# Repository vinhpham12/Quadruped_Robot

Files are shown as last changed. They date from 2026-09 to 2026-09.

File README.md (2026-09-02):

# Quadruped_Robot
A custom-designed 12-DOF quadruped robot platform featuring a modular 3D-printed chassis and a dedicated embedded controller board.

## Project Structure

* **hardware/**: 
  * `cad/`: Mechanical assembly, STEP files, and 3D printable STL files (SolidWorks).
  * `pcb/`: Custom mainboard schematics, PCB layout, and gerber files (KiCad).

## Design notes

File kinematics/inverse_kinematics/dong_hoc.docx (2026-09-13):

CHÂN TRÁI TRƯỚC

i | θ_i | d_i | a_(i-1) | α_(i-1)
1 | -90+θ_1 | L_0 | L_1 | -90
2 | θ_2 | 0 | 0 | 90
3 | θ_3 | 0 | L_3 | 0
4 | 0 | 0 | L_4 | 0

CHÂN PHẢI TRƯỚC

i | θ_i | d_i | a_(i-1) | α_(i-1)
1 | -90+θ_1 | L_0 | L_1 | -90
2 | θ_2 | 0 | 0 | 90
3 | θ_3 | 0 | L_3 | 0
4 | 0 | 0 | L_4 | 0

CHÂN TRÁI SAU

i | θ_i | d_i | a_(i-1) | α_(i-1)
1 | -90+θ_1 | L_0 | L_1 | -90
2 | θ_2 | 0 | 0 | 90
3 | θ_3 | 0 | L_3 | 0
4 | 0 | 0 | L_4 | 0

CHÂN PHẢI SAU

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

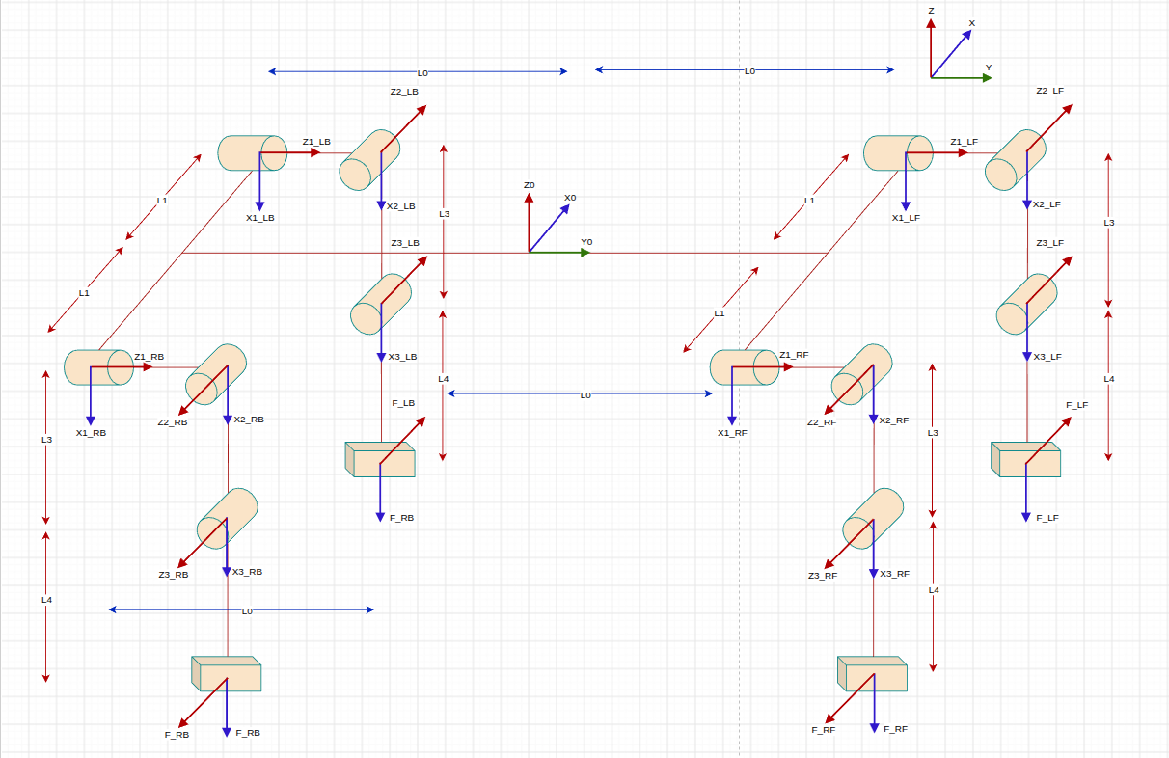
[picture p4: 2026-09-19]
kinematics/inverse_kinematics/Pasted image.png

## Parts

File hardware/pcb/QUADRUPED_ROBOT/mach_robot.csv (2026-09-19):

Reference | Qty | Value | DNP | Exclude from BOM | Exclude from Board | Exclude from Simulation | Exclude from Position Files | Footprint | Datasheet
C1,C2 | 2 | 22pF |  |  |  |  | ${EXCLUDE_FROM_POS_FILES} | Capacitor_SMD:C_0805_2012Metric
C3,C6,C7,C8,C12,C13,C14,C15,C16,C17,C18,C19,C22,C23,C25,C27,C28,C31,C34,C35,C36,C37,C38,C39,C40,C41,C42,C43,C44,C45,C46,C47,C48,C52,C53,C54,C56,C57,C64 | 39 | 100nF |  |  |  |  | ${EXCLUDE_FROM_POS_FILES} | Capacitor_SMD:C_0805_2012Metric
C4,C5 | 2 | 2.2uF |  |  |  |  | ${EXCLUDE_FROM_POS_FILES} | Capacitor_SMD:C_0805_2012Metric
C10 | 1 | 470uF |  |  |  |  | ${EXCLUDE_FROM_POS_FILES} | Capacitor_THT:CP_Radial_D10.0mm_P5.00mm
C11,C26,C50 | 3 | 1uF |  |  |  |  | ${EXCLUDE_FROM_POS_FILES} | Capacitor_SMD:C_0805_2012Metric
C20,C24 | 2 | 1nF |  |  |  |  | ${EXCLUDE_FROM_POS_FILES} | Capacitor_SMD:C_0805_2012Metric
C21 | 1 | 4.7uF |  |  |  |  | ${EXCLUDE_FROM_POS_FILES} | Capacitor_SMD:C_0805_2012Metric
C30,C49,C51 | 3 | 470uF |  |  |  |  | ${EXCLUDE_FROM_POS_FILES} | Capacitor_SMD:CP_Elec_8x10
C32 | 1 | 200uF |  |  |  |  | ${EXCLUDE_FROM_POS_FILES} | Capacitor_Tantalum_SMD:CP_EIA-7343-31_Kemet-D_HandSolder
C33,C58,C60,C61,C62,C63 | 6 | 470uF |  |  |  |  | ${EXCLUDE_FROM_POS_FILES} | Capacitor_Tantalum_SMD:CP_EIA-7343-31_Kemet-D_HandSolder
C55 | 1 | 10uF |  |  |  |  | ${EXCLUDE_FROM_POS_FILES} | Capacitor_SMD:C_0805_2012Metric
C59 | 1 | 10nF |  |  |  |  | ${EXCLUDE_FROM_POS_FILES} | Capacitor_SMD:C_0805_2012Metric
D1,D2,D7,D8,D9,D14 | 6 | LED |  |  |  |  | ${EXCLUDE_FROM_POS_FILES} | LED_SMD:LED_0805_2012Metric
D3 | 1 | D_Zener |  |  |  |  | ${EXCLUDE_FROM_POS_FILES} | Diode_SMD:D_0805_2012Metric
D4 | 1 | SS54 |  |  |  |  | ${EXCLUDE_FROM_POS_FILES} | Diode_SMD:D_SMC
D5 | 1 | SMAJ5.0A |  |  |  |  | ${EXCLUDE_FROM_POS_FILES} | Diode_SMD:D_SMA | https://www.littelfuse.com/media?itemid=75e32973-b177-4ee3-a0ff-cedaf1abdb93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
D6 | 1 | SS1040 |  |  |  |  | ${EXCLUDE_FROM_POS_FILES} | Diode_SMD:D_SMC
D10 | 1 | LED_G |  |  |  |  | ${EXCLUDE_FROM_POS_FILES} | LED_SMD:LED_0805_2012Metric
D11 | 1 | LED_R |  |  |  |  | ${EXCLUDE_FROM_POS_FILES} | LED_SMD:LED_0805_2012Metric
D13 | 1 | SMBJ6.5A |  |  |  |  | ${EXCLUDE_FROM_POS_FILES} | Diode_SMD:D_SMB
F1,F2 | 2 | Fuse |  |  |  |  | ${EXCLUDE_FROM_POS_FILES} | Fuse:Fuseholder_Littelfuse_100_series_5x20mm
J1 | 1 | Conn_01x03_Socket |  |  |  |  | ${EXCLUDE_FROM_POS_FILES} | Connector_PinSocket_2.54mm:PinSocket_1x03_P2.54mm_Vertical
J2 | 1 | Conn_01x04_Pin |  |  |  |  | ${EXCLUDE_FROM_POS_FILES} | Connector_PinSocket_2.54mm:PinSocket_1x04_P2.54mm_Vertical
J3 | 1 | SWITCH_POWER |  |  |  |  | ${EXCLUDE_FROM_POS_FILES} | Connector_PinHeader_2.54mm:PinHeader_1x02_P2.54mm_Vertical
J4,J11,J12,J13,J14,J15,J16,J17,J18,J19,J20,J21,J22 | 13 | Conn_01x03_Pin |  |  |  |  | ${EXCLUDE_FROM_POS_FILES} | Connector_PinHeader_2.54mm:PinHeader_1x03_P2.54mm_Vertical
J5,J10 | 2 | PIN |  |  |  |  | ${EXCLUDE_FROM_POS_FILES} | my_library:TerminalBlock_Phoenix_MKDS-1,5-2-5.08_1x02_P5.08mm_Horizontal
J6 | 1 | USB_C_Receptacle_USB2.0_16P |  |  |  |  | ${EXCLUDE_FROM_POS_FILES} | Connector_USB:USB_C_Receptacle_Amphenol_12401948E412A | https://www.usb.org/sites/default/files/documents/usb_type-c.zip
J7 | 1 | USB_A |  |  |  |  | ${EXCLUDE_FROM_POS_FILES} | Connector_USB:USB_A_Molex_67643_Horizontal
J8 | 1 | Conn_01x05_Pin |  |  |  |  | ${EXCLUDE_FROM_POS_FILES} | Connector_PinSocket_2.54mm:PinSocket_1x05_P2.54mm_Vertical
J9 | 1 | JETSON |  |  |  |  | ${EXCLUDE_FROM_POS_FILES} | my_library:TerminalBlock_Phoenix_MKDS-1,5-2-5.08_1x02_P5.08mm_Horizontal
L1 | 1 | 10uH |  |  |  |  | ${EXCLUDE_FROM_POS_FILES} | Inductor_SMD:L_12x12mm_H6mm
L2 | 1 | 33uH |  |  |  |  | ${EXCLUDE_FROM_POS_FILES} | Inductor_SMD:L_12x12mm_H6mm
Q1 | 1 | AO4485 |  |  |  |  | ${EXCLUDE_FROM_POS_FILES} | Package_SO:SOIC-8_3.9x4.9mm_P1.27mm
Q2,Q3 | 2 | BC847 |  |  |  |  | ${EXCLUDE_FROM_POS_FILES} | Package_TO_SOT_SMD:SOT-23 | http://www.infineon.com/dgdl/Infineon-BC847SERIES_BC848SERIES_BC849SERIES_BC850SERIES-DS-v01_01-en.pdf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
R1 | 1 | 0 |  |  |  |  | ${EXCLUDE_FROM_POS_FILES} | Resistor_SMD:R_0805_2012Metric
R2,R3,R4,R50,R51,R52,R54,R55,R59,R62 | 10 | 10K |  |  |  |  | ${EXCLUDE_FROM_POS_FILES} | Resistor_SMD:R_0805_2012Metric
R5,R8 | 2 | 10m |  |  |  |  | ${EXCLUDE_FROM_POS_FILES} | Resistor_SMD:R_2512_6332Metric
R6 | 1 | 3K |  |  |  |  | ${EXCLUDE_FROM_POS_FILES} | Resistor_SMD:R_0805_2012Metric
R7 | 1 | 50m |  |  |  |  | ${EXCLUDE_FROM_POS_FILES} | Resistor_SMD:R_2512_6332Metric
R9,R10,R38,R41,R42,R43 | 6 | 1K |  |  |  |  | ${EXCLUDE_FROM_POS_FILES} | Resistor_SMD:R_0805_2012Metric
R11 | 1 | 100K |  |  |  |  | ${EXCLUDE_FROM_POS_FILES} | Resistor_SMD:R_0805_2012Metric
R12 | 1 | 5.9k |  |  |  |  | ${EXCLUDE_FROM_POS_FILES} | Resistor_SMD:R_0805_2012Metric
R13,R26,R27,R28,R29,R30,R31,R32,R33,R34,R35,R36,R37 | 13 | 10k |  |  |  |  | ${EXCLUDE_FROM_POS_FILES} | Resistor_SMD:R_0805_2012Metric
R14,R15,R16,R17,R18,R19,R20,R21,R22,R23,R24,R25 | 12 | 100R |  |  |  |  | ${EXCLUDE_FROM_POS_FILES} | Resistor_SMD:R_0805_2012Metric
R39,R40 | 2 | 5.1K |  |  |  |  | ${EXCLUDE_FROM_POS_FILES} | Resistor_SMD:R_0805_2012Metric
R44,R49 | 2 | 270R |  |  |  |  | ${EXCLUDE_FROM_POS_FILES} | Resistor_SMD:R_0805_2012Metric
R45,R48 | 2 | 100k |  |  |  |  | ${EXCLUDE_FROM_POS_FILES} | Resistor_SMD:R_0805_2012Metric
R46,R47 | 2 | 47K |  |  |  |  | ${EXCLUDE_FROM_POS_FILES} | Resistor_SMD:R_0805_2012Metric
R53 | 1 | 20K |  |  |  |  | ${EXCLUDE_FROM_POS_FILES} | Resistor_SMD:R_0805_2012Metric
R56,R63 | 2 | 30K |  |  |  |  | ${EXCLUDE_FROM_POS_FILES} | Resistor_SMD:R_0805_2012Metric
R58,R60 | 2 | 4.7k |  |  |  |  | ${EXCLUDE_FROM_POS_FILES} | Resistor_SMD:R_0805_2012Metric
R61,R64 | 2 | 4.7K |  |  |  |  | ${EXCLUDE_FROM_POS_FILES} | Resistor_SMD:R_0805_2012Metric
SW1 | 1 | SW_Push |  |  |  |  | ${EXCLUDE_FROM_POS_FILES} | my_library:SW_SMD_3x6mm
U1 | 1 | XL4016 |  |  |  |  | ${EXCLUDE_FROM_POS_FILES} | Package_TO_SOT_SMD:TO-263-5_TabPin3 | http://www.xlsemi.net/datasheet/XL4015%20datasheet-English.pdf
U2 | 1 | STM32F723ZETx |  |  |  |  | ${EXCLUDE_FROM_POS_FILES} | Package_QFP:LQFP-144_20x20mm_P0.5mm | https://www.st.com/resource/en/datasheet/stm32f723ze.pdf
U3 | 1 | TPS5430DDA |  |  |  |  | ${EXCLUDE_FROM_POS_FILES} | Package_SO:TI_SO-PowerPAD-8_ThermalVias | http://www.ti.com/lit/ds/symlink/tps5430.pdf
U4 | 1 | USBLC6-2SC6 |  |  |  |  | ${EXCLUDE_FROM_POS_FILES} | Package_TO_SOT_SMD:SOT-23-6 | https://www.st.com/resource/en/datasheet/usblc6-2.pdf
U5 | 1 | INA3221 |  |  |  |  | ${EXCLUDE_FROM_POS_FILES} | Package_DFN_QFN:Texas_RGV0016A_VQFN-16-1EP_4x4mm_P0.65mm_EP2.1x2.1mm | http://www.ti.com/lit/ds/symlink/ina3221.pdf
Y1 | 1 | 25MHz |  |  |  |  | ${EXCLUDE_FROM_POS_FILES} | Crystal:Crystal_HC49-U_Vertical

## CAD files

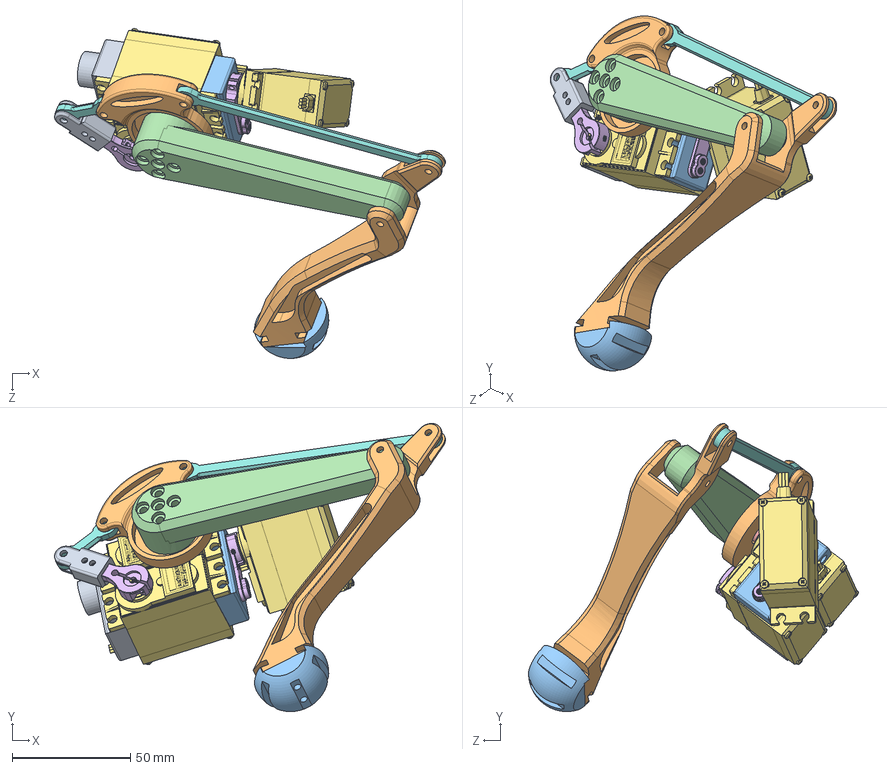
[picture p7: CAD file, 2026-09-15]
hardware/cad/left_foot_after.SLDASM
165.4 x 121.9 x 139.6 mm
MirrorPart78
Servo disc
SERVO ARM HORN 25T ALUMINIUM.step x 2
mg996R_v2.step x 3
noi_3 x 2
noi_chan_1
arm_mod
foot

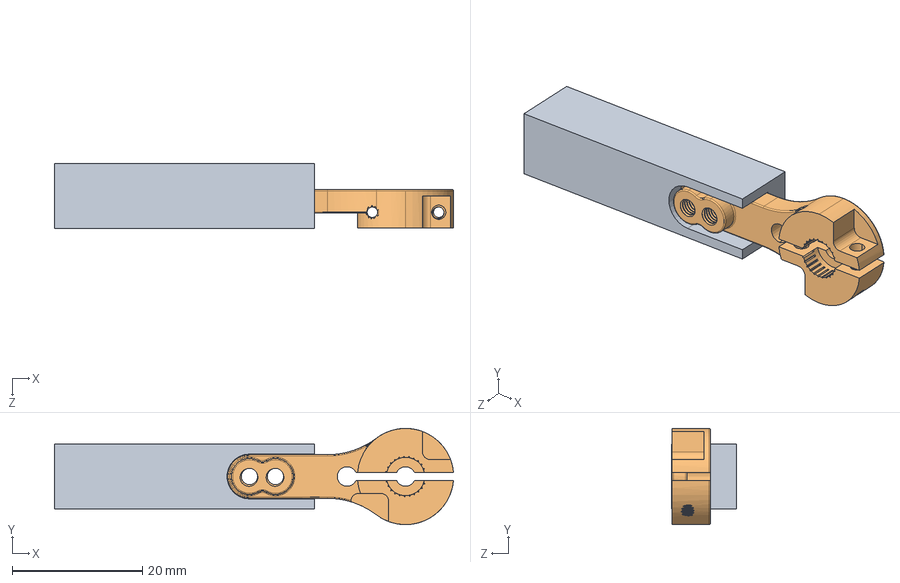
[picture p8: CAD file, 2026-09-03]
hardware/cad/SERVO ARM HORN 25T ALUMINIUM/chan.SLDASM
61.3 x 14.8 x 10.0 mm
noi_chan_1
SERVO ARM HORN 25T ALUMINIUM.step

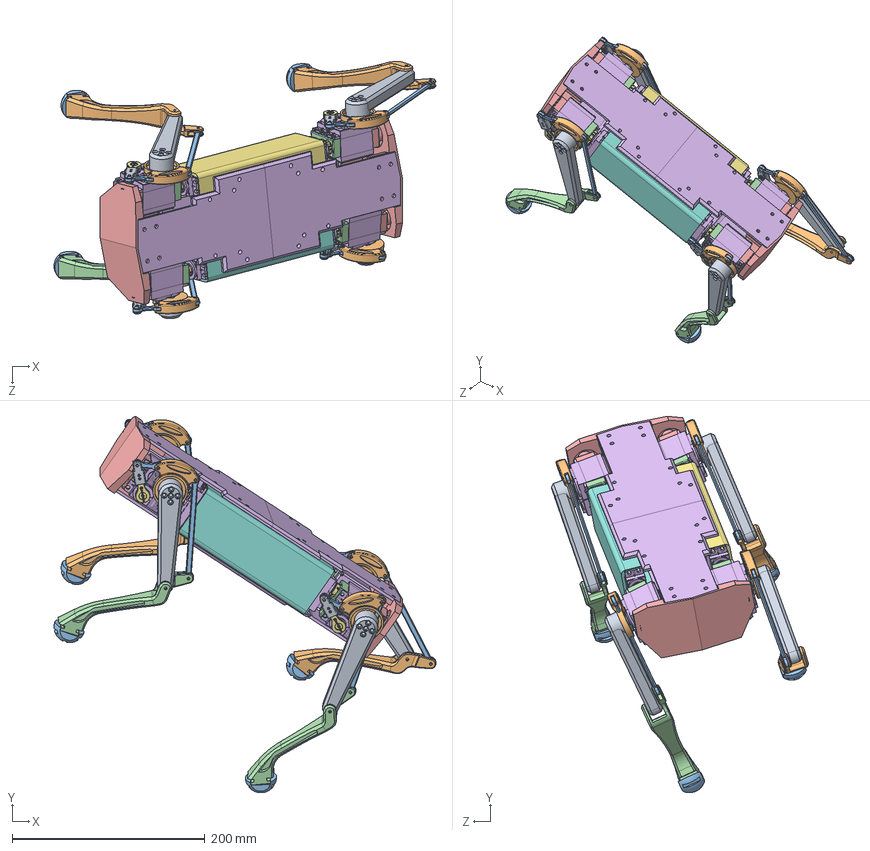
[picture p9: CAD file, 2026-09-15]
hardware/cad/final.SLDASM
395.9 x 390.1 x 266.6 mm
noi_3 x 8
mg996R_v2.step x 12
SERVO ARM HORN 25T ALUMINIUM.step x 8
Servo disc x 4
noi_chan_1 x 4
arm_mod x 4
foot x 4
MirrorPart78 x 2
dau_noi x 2

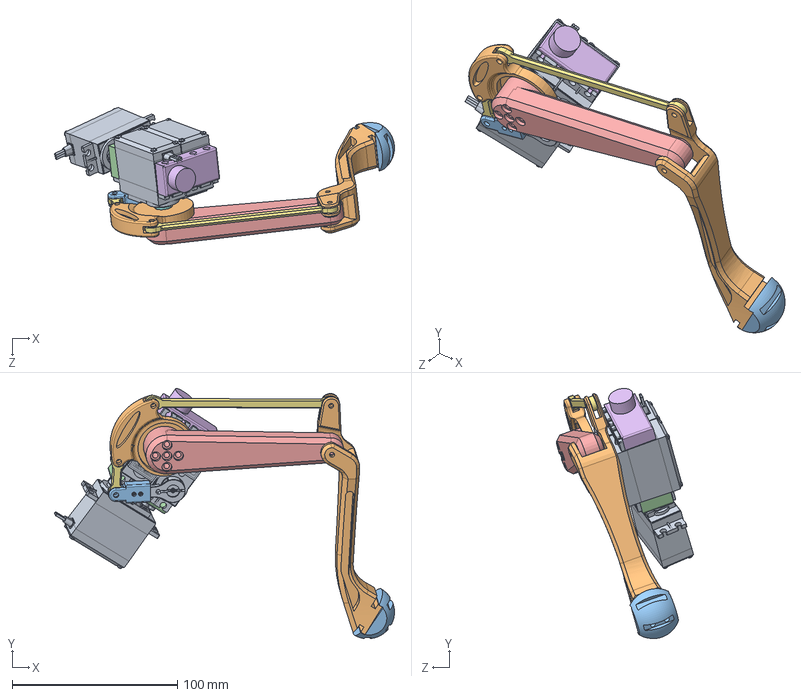
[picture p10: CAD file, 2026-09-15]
hardware/cad/left_foot_back.SLDASM
206.0 x 151.5 x 83.1 mm
mg996R_v2.step x 3
MirrorPart78
noi_chan_1
noi_3 x 2
Servo disc
SERVO ARM HORN 25T ALUMINIUM.step x 2
arm_mod
foot

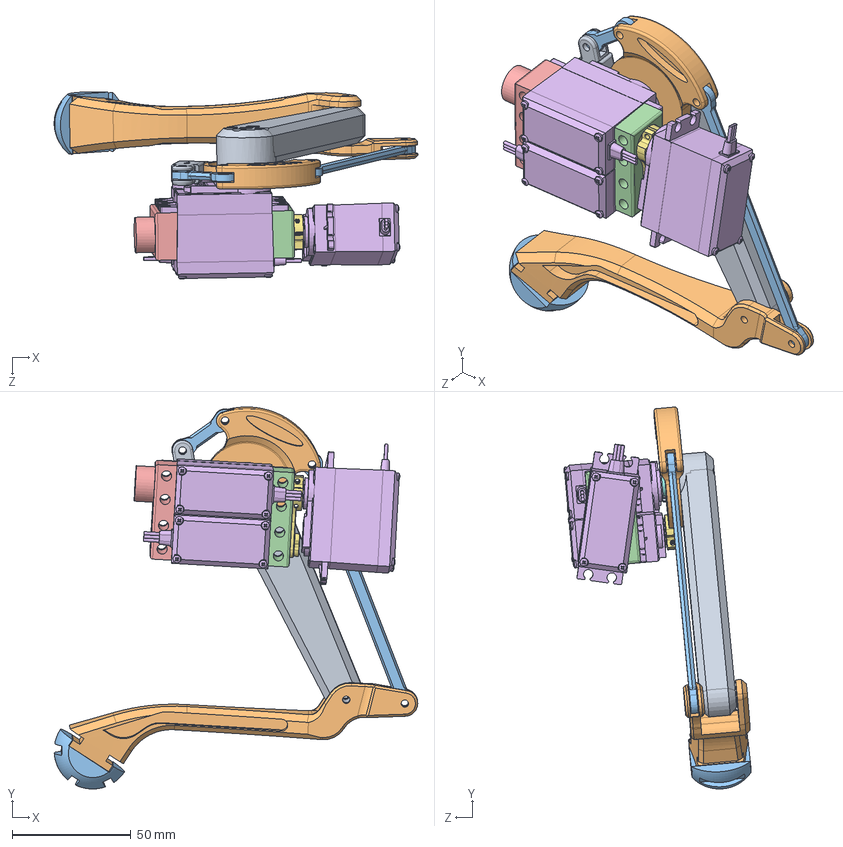
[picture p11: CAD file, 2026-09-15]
hardware/cad/right_foot_after.SLDASM
153.1 x 160.8 x 78.9 mm
noi_3 x 2
mg996R_v2.step x 3
SERVO ARM HORN 25T ALUMINIUM.step x 2
Servo disc
noi_chan_1
arm_mod
foot

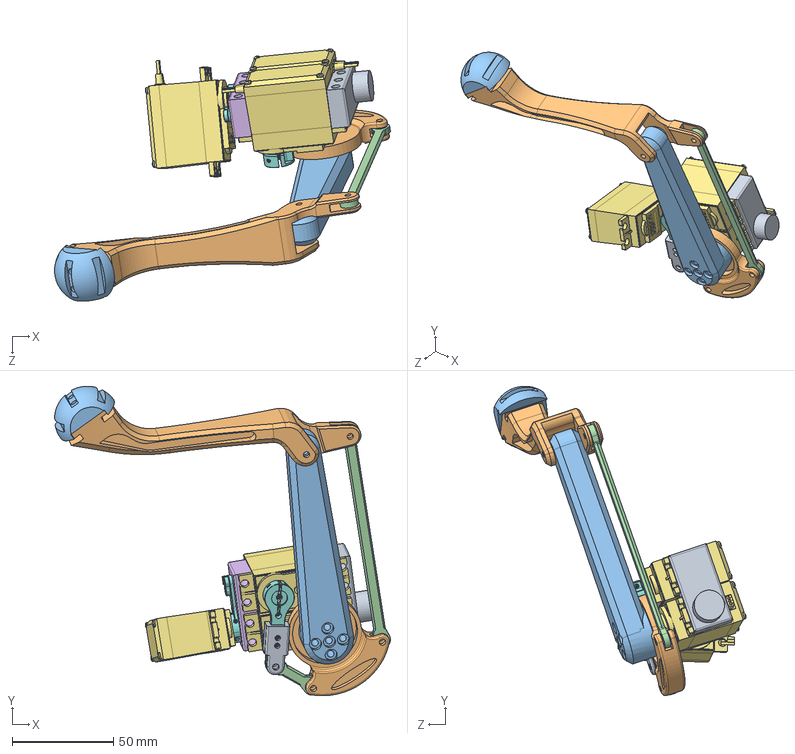
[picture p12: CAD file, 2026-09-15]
hardware/cad/Right_foot_bacl.SLDASM
165.5 x 152.5 x 124.3 mm
noi_3 x 2
Servo disc
mg996R_v2.step x 3
SERVO ARM HORN 25T ALUMINIUM.step x 2
noi_chan_1
arm_mod
foot

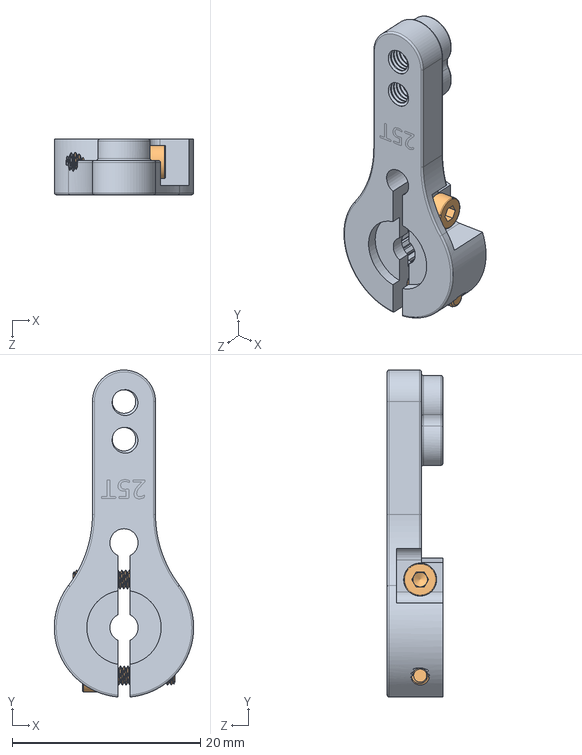
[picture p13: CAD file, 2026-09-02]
hardware/cad/SERVO ARM HORN 25T ALUMINIUM/SERVO ARM HORN WITH FASTENERS.SLDASM
14.8 x 34.7 x 5.90 mm
SERVO ARM HORN 25T ALUMINIUM
M2 CAP HEAD SOCKET SCREW x 2

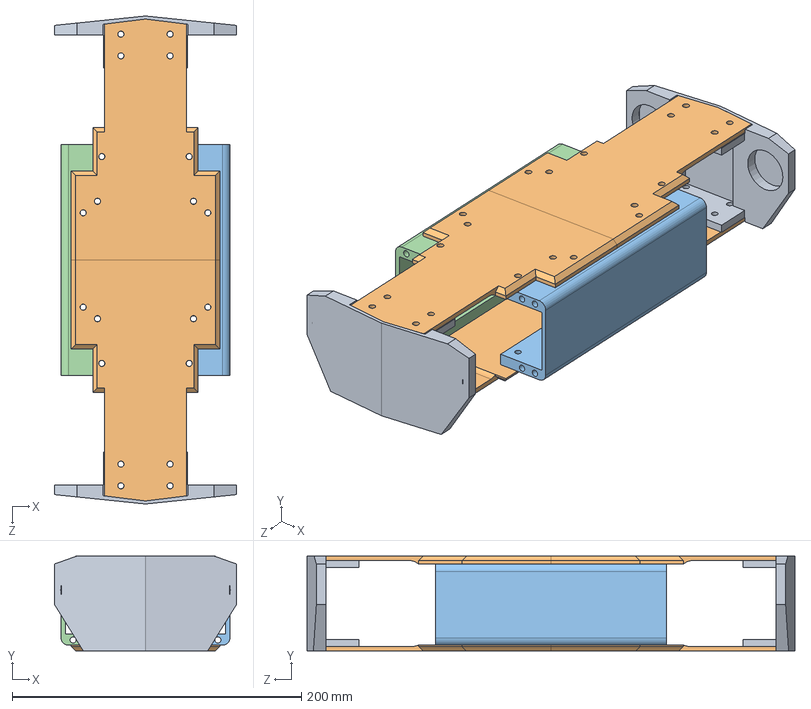
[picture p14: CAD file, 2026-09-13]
hardware/cad/khung.SLDASM
126.0 x 65.5 x 337.4 mm
dau_noi x 2

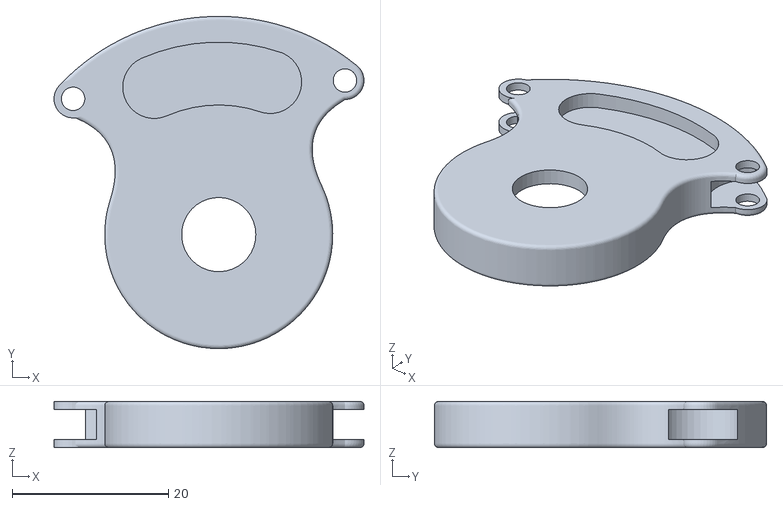
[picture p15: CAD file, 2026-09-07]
hardware/cad/in_3d/arm_mod_L_2.STL
39.7 x 42.5 x 5.90

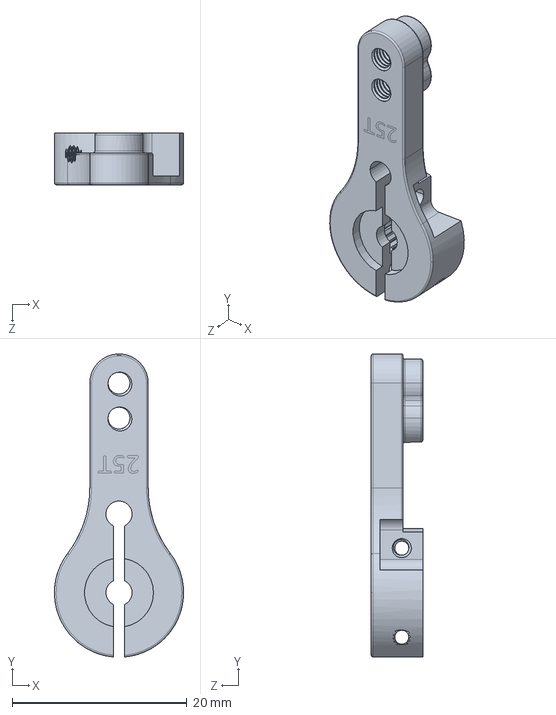
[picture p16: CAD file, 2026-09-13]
hardware/cad/SERVO ARM HORN 25T ALUMINIUM/SERVO ARM HORN 25T ALUMINIUM.step.SLDPRT
14.8 x 34.7 x 5.90 mm

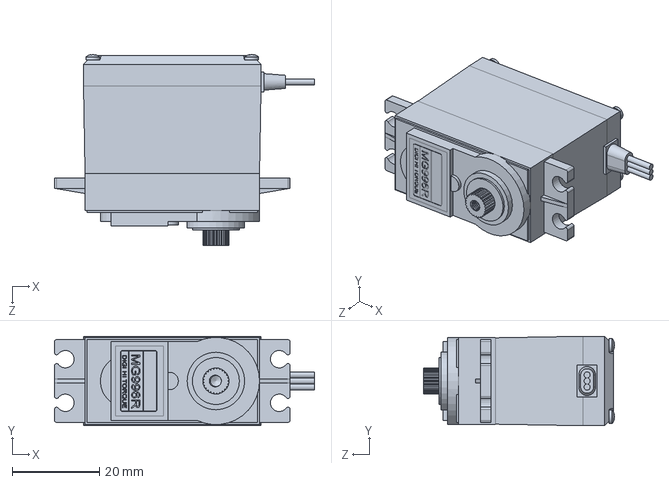
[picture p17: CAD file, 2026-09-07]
hardware/cad/Servo disk/mg996R_v2.step.SLDPRT
59.6 x 20.5 x 43.8 mm

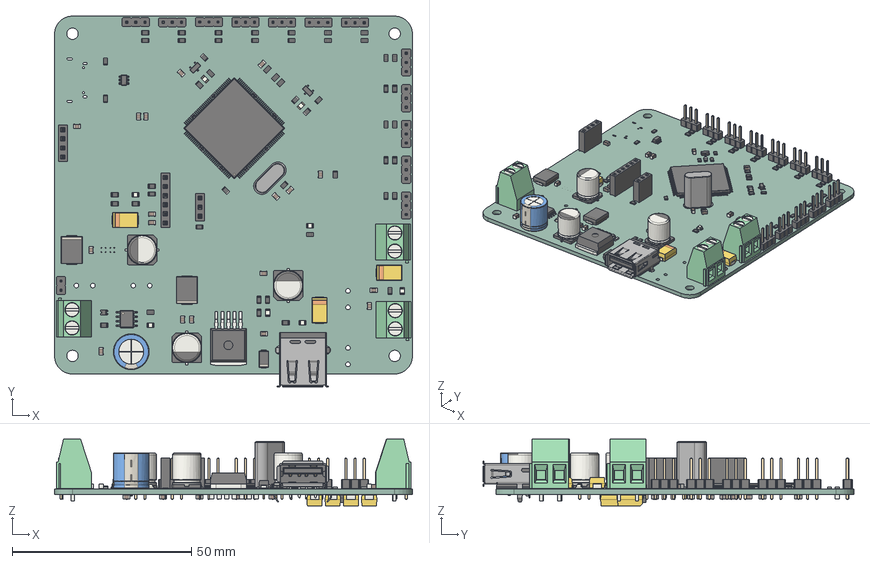
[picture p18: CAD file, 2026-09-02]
hardware/pcb/QUADRUPED_ROBOT/mach_robot.step
100.0 x 103.6 x 18.6 mm
SOT-23 x 2
C_0805_2012Metric x 50
R_0805_2012Metric x 52
CP_Elec_8x10 x 3
LED_0805_2012Metric x 8
LQFP-144_20x20mm_P0.5mm
PinHeader_1x03_P254mm_Vertical x 12
SOT-23-6
D_SMA
CP_Radial_D100mm_P500mm
CP_EIA_7343_31_Kemet_D x 7
TerminalBlock_Phoenix_MKDS-1,5-2-5.08_1x02_P5.08mm_Horizontal x 3
D_0805
PinSocket_1x06_P2.54mm_Vertical
SOIC-8_3.9x4.9mm_P1.27mm
a648ce37-9c39-11ed-93f0-dde97e994e83_part
a648ce38-9c39-11ed-93f0-dde97e994e83_part
a648ce39-9c39-11ed-93f0-dde97e994e83_part
USB_A_Molex_67643_Horizontal
Crystal_HC49-U_Vertical
PinHeader_1x02_P254mm_Vertical
PinSocket_1x03_P2.54mm_Vertical
D_SMC x 2
PinSocket_1x04_P2.54mm_Vertical
D_SMB
mach_robot-unsaved-export-i5f7Bk_PCB

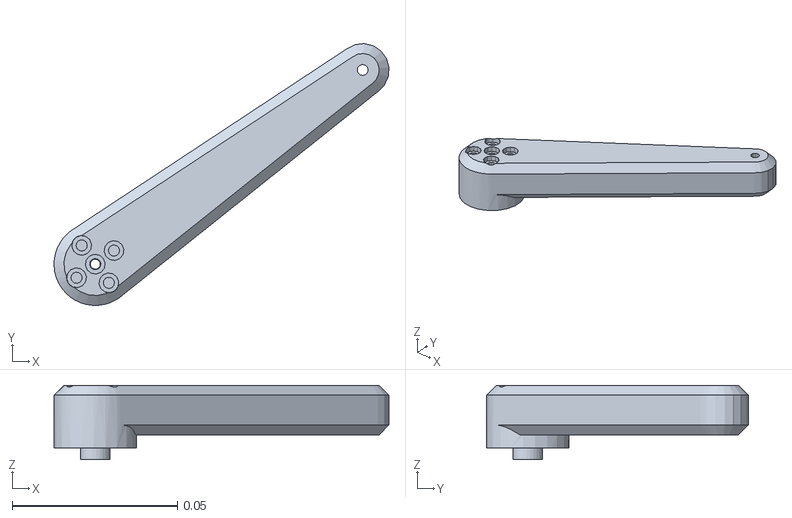
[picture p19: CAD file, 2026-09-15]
URDF/meshes/Thigh_LB.STL
0.101 x 0.0792 x 0.0225

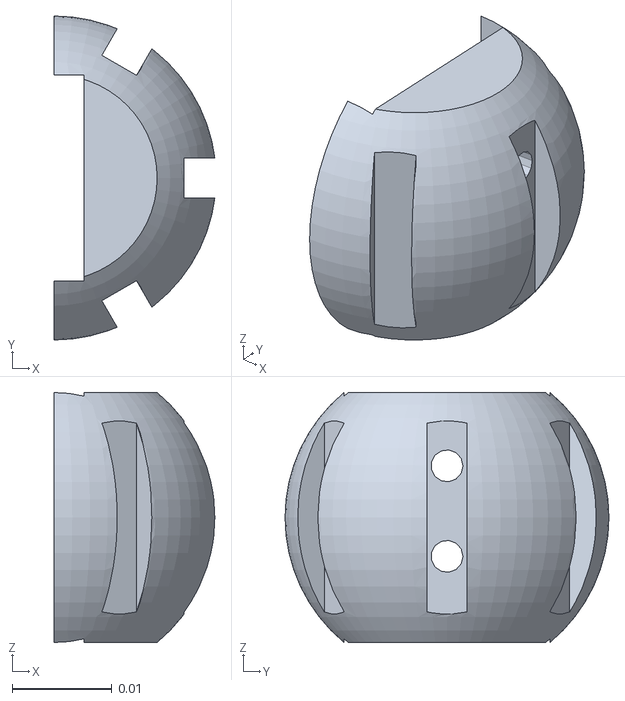
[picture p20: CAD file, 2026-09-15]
URDF_1/meshes/Foot_LF.STL
0.0161 x 0.0324 x 0.025

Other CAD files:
hardware/cad/SERVO ARM HORN 25T ALUMINIUM/Mirrorchan.SLDASM
hardware/cad/SERVO ARM HORN 25T ALUMINIUM/Mirrorchan1.SLDASM
hardware/cad/in_3d/noi_chan_1.STL
hardware/cad/Part75.SLDPRT
URDF/meshes/Calf_LB.STL
URDF/meshes/Calf_LF.STL
URDF/meshes/Calf_RB.STL
URDF/meshes/Calf_RF.STL
URDF/meshes/Foot_LB.STL
URDF/meshes/Foot_LF.STL
URDF/meshes/Foot_RB.STL
URDF/meshes/Foot_RF.STL
URDF/meshes/Hip_LB.STL
URDF/meshes/Hip_LF.STL
URDF/meshes/Hip_RB.STL
URDF/meshes/Thigh_LF.STL
URDF/meshes/Thigh_RB.STL
URDF/meshes/Thigh_RF.STL
URDF/meshes/base_link.STL
URDF/meshes/hip_RF.STL
URDF_1/meshes/Calf_LB.STL
URDF_1/meshes/Calf_LF.STL
URDF_1/meshes/Calf_RB.STL
URDF_1/meshes/Calf_RF.STL
URDF_1/meshes/Foot_LB.STL
URDF_1/meshes/Foot_RB.STL
URDF_1/meshes/Foot_RF.STL
URDF_1/meshes/Hip_LB.STL
URDF_1/meshes/Hip_LF.STL
URDF_1/meshes/Hip_RB.STL
URDF_1/meshes/Thigh_LB.STL
URDF_1/meshes/Thigh_LF.STL
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

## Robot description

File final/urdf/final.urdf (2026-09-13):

<?xml version="1.0" encoding="utf-8"?>
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
<robot name="final">
  <link name="base_link">
    <inertial>
      <origin xyz="0.165469810038744 -0.470844613530659 0.264323367068224" rpy="0 0 0" />
      <mass value="0.326547449294338" />
      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
    </inertial>
    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
  </link>
  <link name="hip_LF">
    <inertial>
      <origin xyz="0.0104971925588967 0.00114288562998305 0.0298079595716109" rpy="0 0 0" />
      <mass value="0.0691270861873928" />
      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
    </inertial>
    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
  </link>
  <joint name="Joint1_LF" type="revolute">
    <origin xyz="0.0828037089815861 -0.530142263822002 0.293885901306255" rpy="-0.705882033003174 1.04313880299812 2.52448464320818" />
    <parent link="base_link" />
    <child link="hip_LF" />
    <axis xyz="0 0 1" />
    <limit lower="-1.57" upper="1.57" effort="1.5" velocity="6" />
  </joint>
  <link name="Thigh_LF">
    <inertial>
      <origin xyz="0.036049231921557 0.0174653680299302 0.0104420538930677" rpy="0 0 0" />
      <mass value="0.0136519262084262" />
      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
    </inertial>
    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
  </link>
  <joint name="Joint2_LF" type="revolute">
    <origin xyz="-0.000103830202143829 0.0255001128999754 0.0199" rpy="-1.5707963267949 0 0.00911492757548553" />
    <parent link="hip_LF" />
    <child link="Thigh_LF" />
    <axis xyz="0 0 1" />
    <limit lower="-1.57" upper="1.57" effort="1.5" velocity="6" />
  </joint>
  <link name="Calf_LF">
    <inertial>
      <origin xyz="0.0401260987407683 -0.0414799951379243 -0.00647647599601348" rpy="0 0 0" />
      <mass value="0.00886599216069645" />
      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
    </inertial>
    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
  </link>
  <joint name="Joint3_LF" type="revolute">
    <origin xyz="0.0899941947746462 0.0436009736916917 0.0238999999999975" rpy="0.155925725989217 0.0091149275754857 0" />
    <parent link="Thigh_LF" />
    <child link="Calf_LF" />
    <axis xyz="0.00911480136175463 -0.155288209919299 -0.987827157075667" />
    <limit lower="-1.57" upper="1.57" effort="1.5" velocity="6" />
  </joint>
  <link name="hip_LB">
    <inertial>
      <origin xyz="0.0105579816568965 -0.000156117223233665 0.0298079671863085" rpy="0 0 0" />
      <mass value="0.0691271473745254" />
      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
    </inertial>
    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
  </link>
  <joint name="Joint1_LB" type="revolute">
    <origin xyz="0.256926339687758 -0.50176821300437 0.220696871077039" rpy="2.43571062058662 1.04313880299812 2.52448464320818" />
    <parent link="base_link" />
    <child link="hip_LB" />
    <axis xyz="0 0 1" />
    <limit lower="-1.57" upper="1.57" effort="1.5" velocity="6" />
  </joint>
  <link name="Thigh_LB">
    <inertial>
      <origin xyz="0.0326193945591627 0.0232499739951309 0.0104420540124198" rpy="0 0 0" />
      <mass value="0.0136519260871885" />
      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
    </inertial>
    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
  </link>
  <joint name="Joint2_LB" type="revolute">
    <origin xyz="0.0022793837699181 -0.0253982468305898 0.0398999999999235" rpy="1.5707963267949 0 0.0844627326260078" />
    <parent link="hip_LB" />
    <child link="Thigh_LB" />
    <axis xyz="0 0 1" />
    <limit lower="-1.57" upper="1.57" effort="1.5" velocity="6" />
  </joint>
  <link name="Calf_LB">
    <inertial>
      <origin xyz="0.0434144582663147 -0.0362416645314376 -0.0132047342874759" rpy="0 0 0" />
      <mass value="0.00886599097543363" />
      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
    </inertial>
    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
  </link>
  <joint name="Joint3_LB" type="revolute">
    <origin xyz="0.0814318625004756 0.0580418106742034 0.0239000001006261" rpy="0 0 0" />
    <parent link="Thigh_LB" />
    <child link="Calf_LB" />
    <axis xyz="0 0 1" />
    <limit lower="-1.57" upper="1.57" effort="1.5" velocity="6" />
  </joint>
  <link name="hip_RB">
    <inertial>
      <origin xyz="0.0105152983393906 0.000962152057977783 0.0298079667384993" rpy="0 0 0" />
      <mass value="0.0691271481987827" />
      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
    </inertial>
    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
  </link>
  <joint name="Joint1_RB" type="revolute">
    <origin xyz="0.255423331114134 -0.416717792411357 0.250093587257239" rpy="2.43571062058662 1.04313880299812 2.52448464320818" />
    <parent link="base_link" />
    <child link="hip_RB" />
    <axis xyz="0 0 1" />
    <limit lower="-1.57" upper="1.57" effort="1.5" velocity="6" />
  </joint>
  <link name="Thigh_RB">
    <inertial>
      <origin xyz="-0.0297626679191992 0.0268098822119125 0.0104420535448091" rpy="0 0 0" />
      <mass value="0.0136519260994359" />
      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
    </inertial>
    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
  </link>
  <joint name="Joint2_RB" type="revolute">
    <origin xyz="0.000334819020600619 0.0254981261046049 0.039899999999996" rpy="1.57079632679489 0 3.13350548107536" />
    <parent link="hip_RB" />
    <child link="Thigh_RB" />
    <axis xyz="0 0 1" />
    <limit lower="-1.57" upper="1.57" effort="1.5" velocity="6" />
  </joint>
  <link name="Calf_RB">
    <inertial>
      <origin xyz="-0.0280790707628065 -0.0490900191801899 -0.0132047471017608" rpy="0 0 0" />
      <mass value="0.00886600238835247" />
      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
    </inertial>
    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
  </link>
  <joint name="Joint3_RB" type="revolute">
    <origin xyz="-0.0743002608384791 0.0669288520694507 0.0238999999999875" rpy="0 0 0" />
    <parent link="Thigh_RB" />
    <child link="Calf_RB" />
    <axis xyz="0 0 -1" />
    <limit lower="-1.57" upper="1.57" effort="1.5" velocity="6" />
  </joint>
  <link name="hip_RF">
    <inertial>
      <origin xyz="0.010399792151054 -0.00182747251492799 0.0298079563673649" rpy="0 0 0" />
      <mass value="0.0691270910624313" />
      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
    </inertial>
    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
  </link>
  <joint name="Joint1_RF" type="revolute">
    <origin xyz="0.081301 -0.44509 0.32328" rpy="-0.70588 1.0431 2.5245" />
    <parent link="base_link" />
    <child link="hip_RF" />
    <axis xyz="0 0 1" />
    <limit lower="-1.57" upper="1.57" effort="1.5" velocity="6" />
  </joint>
  <link name="Thigh_RF">
    <inertial>
      <origin xyz="0.0312504715443228 -0.025059812769555 0.0104420535390137" rpy="0 0 0" />
      <mass value="0.0136519260754069" />
      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
    </inertial>
    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
  </link>
  <joint name="Joint2_RF" type="revolute">
    <origin xyz="-0.0017748 -0.025438 0.0199" rpy="1.5708 0 -0.074698" />
    <parent link="hip_RF" />
    <child link="Thigh_RF" />
    <axis xyz="0 0 1" />
    <limit lower="-1.57" upper="1.57" effort="1.5" velocity="6" />
  </joint>
  <link name="Calf_RF">
    <inertial>
      <origin xyz="0.037086446197333 0.0426949252378612 -0.0132047524388045" rpy="0 0 0" />
      <mass value="0.00886601403821361" />
      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
    </inertial>
    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
  </link>
  <joint name="Joint3_RF" type="revolute">
    <origin xyz="0.078014 -0.06256 0.0239" rpy="0 0 0" />
    <parent link="Thigh_RF" />
    <child link="Calf_RF" />
    <axis xyz="0 0 -1" />
    <limit lower="-1.57" upper="1.57" effort="1.5" velocity="6" />
  </joint>
</robot>

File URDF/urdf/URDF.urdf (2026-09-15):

<?xml version="1.0" encoding="utf-8"?>
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
<robot name="URDF">
  <link name="base_link">
    <inertial>
      <origin xyz="-9.00283980698191E-09 5.37260734512213E-09 0.0004696376772092" rpy="0 0 0" />
      <mass value="0.326547449294338" />
      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
    </inertial>
    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
  </link>
  <link name="hip_RF">
    <inertial>
      <origin xyz="0.01043789785135 -0.00182747499403901 0.0298079563378445" rpy="0 0 0" />
      <mass value="0.0691270911282823" />
      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
    </inertial>
    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
  </link>
  <joint name="Joint1_RF" type="revolute">
    <origin xyz="-0.0449999975183671 -0.0954992296169629 0.00938098015422906" rpy="1.5707963267949 1.5707963267949 0" />
    <parent link="base_link" />
    <child link="hip_RF" />
    <axis xyz="0 0 -1" />
    <limit lower="-1.57" upper="1.57" effort="1.5" velocity="6" />
  </joint>
  <link name="Thigh_RF">
    <inertial>
      <origin xyz="0.032280431807894 -0.0236802430912848 0.0104420535363001" rpy="0 0 0" />
      <mass value="0.013651926085773" />
      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
    </inertial>
    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
  </link>
  <joint name="Joint2_RF" type="revolute">
    <origin xyz="-0.00173667361422397 -0.0254384909655809 0.0198618942938599" rpy="1.5707963267949 0 -0.0746977131182897" />
    <parent link="hip_RF" />
    <child link="Thigh_RF" />
    <axis xyz="0 0 -1" />
    <limit lower="-1.57" upper="1.57" effort="1.5" velocity="6" />
  </joint>
  <link name="Calf_RF">
    <inertial>
      <origin xyz="0.0373951602098321 0.0424247926702395 0.00939524740905079" rpy="0 0 0" />
      <mass value="0.00886601436486069" />
      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
    </inertial>
    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
  </link>
  <joint name="Joint3_RF" type="revolute">
    <origin xyz="0.0805856649939703 -0.0591729658721312 0.00130000000000041" rpy="0 0 0" />
    <parent link="Thigh_RF" />
    <child link="Calf_RF" />
    <axis xyz="0 0 -1" />
    <limit lower="-1.57" upper="1.57" effort="1.5" velocity="6" />
  </joint>
  <link name="Foot_RF">
    <inertial>
      <origin xyz="-0.00583271260362817 -6.02953798001238E-12 0.000153322639481396" rpy="0 0 0" />
      <mass value="0.00230350114254969" />
      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
    </inertial>
    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
  </link>
  <joint name="Joint4_RF" type="fixed">
    <origin xyz="0.0849986200651742 0.0827272177698522 0.00992243475665372" rpy="0 0 0.0695608286554116" />
    <parent link="Calf_RF" />
    <child link="Foot_RF" />
    <axis xyz="0 0 0" />
  </joint>
  <link name="Hip_LB">
    <inertial>
      <origin xyz="0.0105452258430738 -0.00104424135186948 0.0298079668931553" rpy="0 0 0" />
      <mass value="0.0691271457278031" />
      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
    </inertial>
    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
  </link>
  <joint name="Joint1_LB" type="revolute">
    <origin xyz="0.0449999975183657 0.0954992296169666 0.00938098015422961" rpy="-1.57079632679533 1.51781885809782 0" />
    <parent link="base_link" />
    <child link="Hip_LB" />
    <axis xyz="0 0 -1" />
    <limit lower="-1.57" upper="1.57" effort="1.5" velocity="6" />
  </joint>
  <link name="Thigh_LB">
    <inertial>
      <origin xyz="0.0324139783823418 0.0234973998967534 0.010442053925429" rpy="0 0 0" />
      <mass value="0.0136519261569896" />
      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
    </inertial>
    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
  </link>
  <joint name="Joint2_LB" type="revolute">
    <origin xyz="0.000166657436375506 -0.0254979846657288 0.0399381057240706" rpy="1.57079632679489 0 0" />
    <parent link="Hip_LB" />
    <child link="Thigh_LB" />
    <axis xyz="0 0 -1" />
    <limit lower="-1.57" upper="1.57" effort="1.5" velocity="6" />
  </joint>
  <link name="Calf_LB">
    <inertial>
      <origin xyz="0.0373755291685387 -0.0424425417626215 0.00939531674951682" rpy="0 0 0" />
      <mass value="0.00886593782689565" />
      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
    </inertial>
    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
  </link>
  <joint name="Joint3_LB" type="revolute">
    <origin xyz="0.0809190598674842 0.0587165140777625 0.00130000001784963" rpy="0 0 0" />
    <parent link="Thigh_LB" />
    <child link="Calf_LB" />
    <axis xyz="0 0 -1" />
    <limit lower="-1.57" upper="1.57" effort="1.5" velocity="6" />
  </joint>
  <link name="Foot_LB">
    <inertial>
      <origin xyz="-0.00583271259474122 8.96259455540616E-12 -0.00015332264911988" rpy="0 0 0" />
      <mass value="0.00230350113970975" />
      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
    </inertial>
    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
  </link>
  <joint name="Joint4_LB" type="fixed">
    <origin xyz="0.0849599453223677 -0.0827669358122232 0.0102631627484333" rpy="0 0 -0.0700282136507758" />
    <parent link="Calf_LB" />
    <child link="Foot_LB" />
    <axis xyz="0 0 0" />
  </joint>
  <link name="Hip_RB">
    <inertial>
      <origin xyz="0.0105452718057615 0.00104790647181918 0.0298079669074503" rpy="0 0 0" />
      <mass value="0.0691271472886633" />
      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
    </inertial>
    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
  </link>
  <joint name="Joint1_RB" type="revolute">
    <origin xyz="-0.0450000024816331 0.0954992296169642 0.00938098015422933" rpy="-1.57079632679485 1.55110721336966 0" />
    <parent link="base_link" />
    <child link="Hip_RB" />
    <axis xyz="0 0 -1" />
    <limit lower="-1.57" upper="1.57" effort="1.5" velocity="6" />
  </joint>
  <link name="Thigh_RB">
    <inertial>
      <origin xyz="0.0294507893394123 -0.0271140048307842 0.0104420443577261" rpy="0 0 0" />
      <mass value="0.0136519261014922" />
      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
    </inertial>
    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
  </link>
  <joint name="Joint2_RB" type="revolute">
    <origin xyz="0.000166704579416199 0.0255007569262712 0.0399381047387575" rpy="-1.5707963267949 0 0" />
    <parent link="Hip_RB" />
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

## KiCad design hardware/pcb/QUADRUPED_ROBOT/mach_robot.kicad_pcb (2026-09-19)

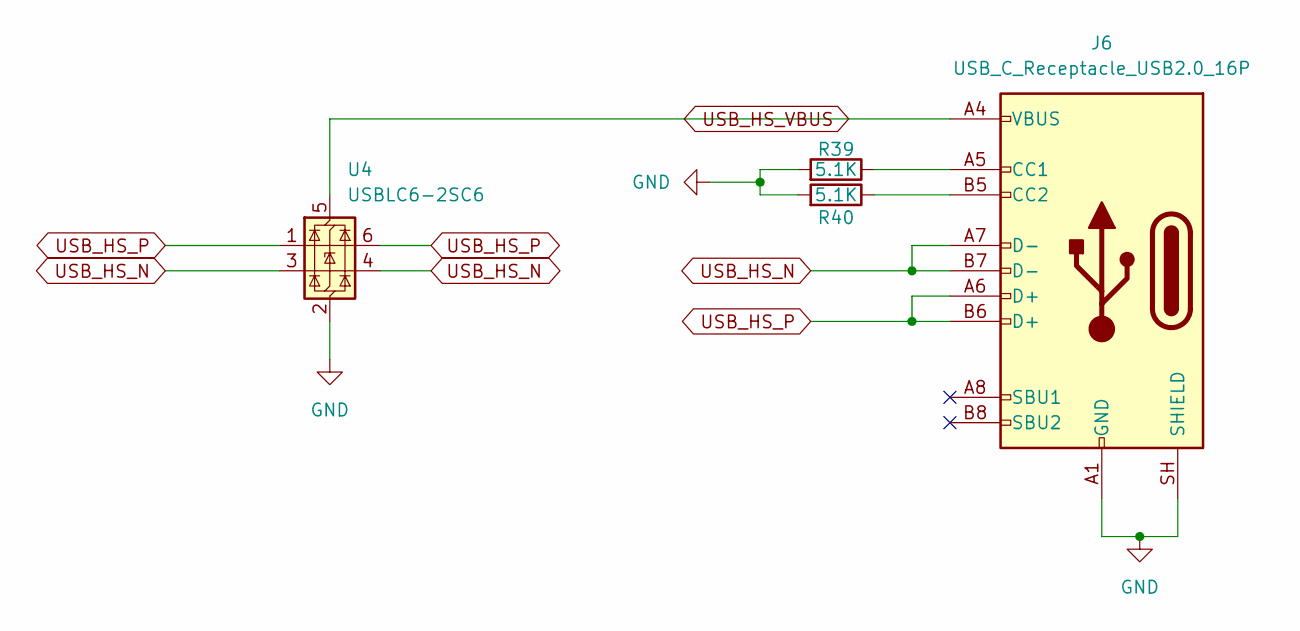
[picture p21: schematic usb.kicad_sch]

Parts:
J6: USB_C_Receptacle_USB2.0_16P; USB_C_Receptacle_Amphenol_12401948E412A
R39, R40: 5.1K; R_0805_2012Metric
U4: USBLC6-2SC6; SOT-23-6

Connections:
GND: J6.A1 (GND), J6.A12 (GND), J6.B1 (GND), J6.B12 (GND), J6.SH (SHIELD), R39.2, R40.2, U4.2 (GND); also elsewhere on the board
unnamed: J6.A5 (CC1), R39.1
unnamed: J6.B5 (CC2), R40.1
USB_HS_N: J6.A7 (D-), J6.B7 (D-), U4.3 (I/O2), U4.4 (I/O2); also elsewhere on the board
USB_HS_P: J6.A6 (D+), J6.B6 (D+), U4.1 (I/O1), U4.6 (I/O1); also elsewhere on the board
USB_HS_VBUS: J6.A4 (VBUS), J6.A9 (VBUS), J6.B4 (VBUS), J6.B9 (VBUS), U4.5 (VBUS); also elsewhere on the board

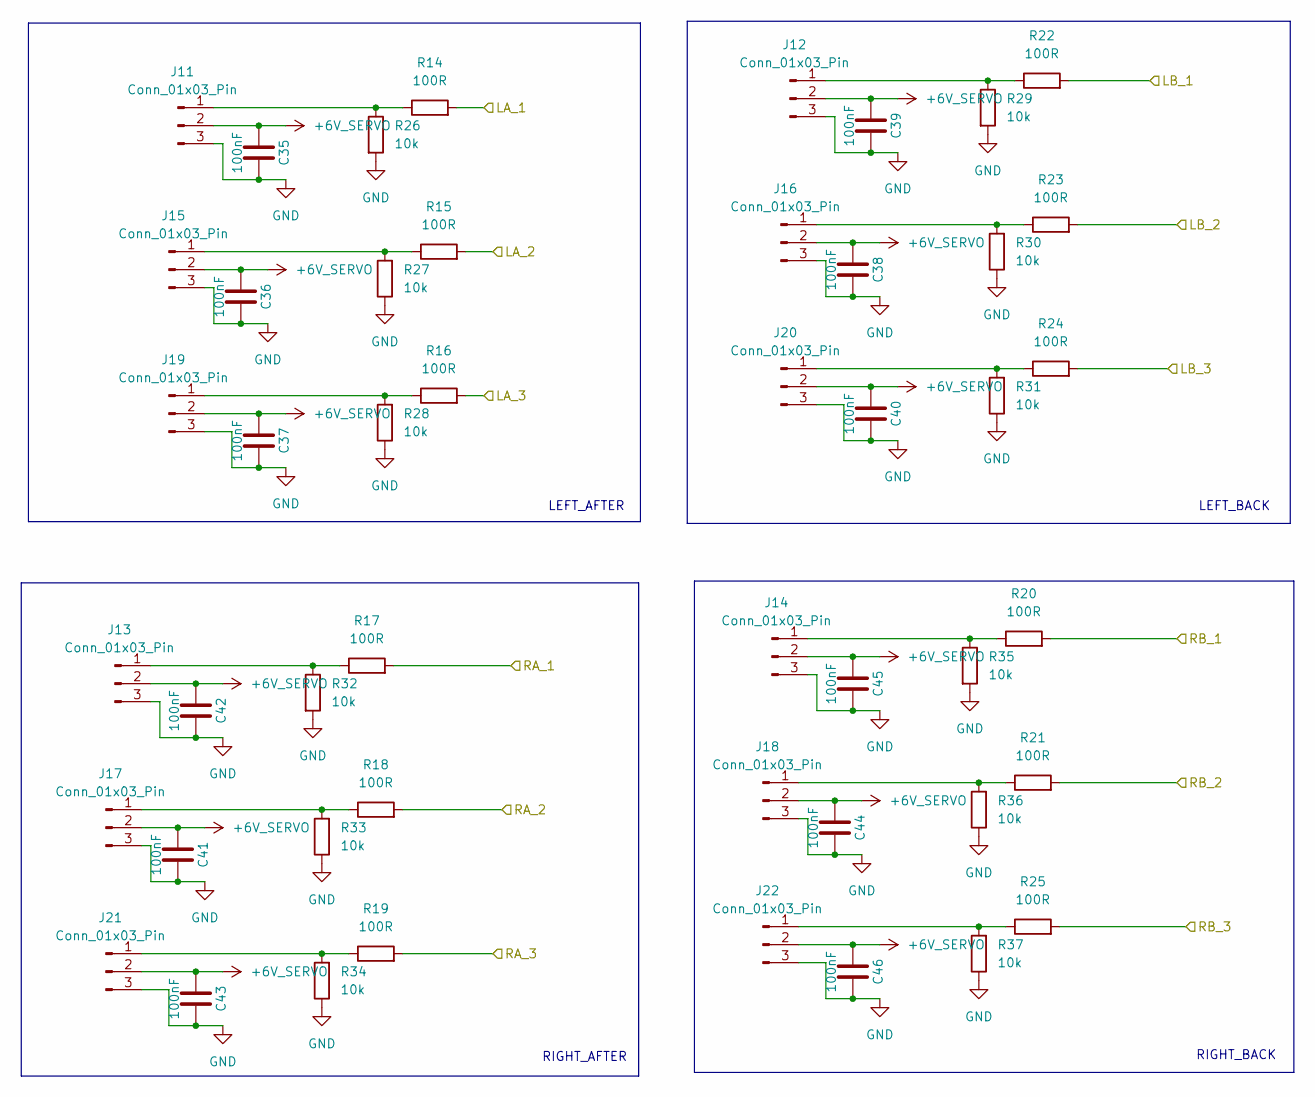
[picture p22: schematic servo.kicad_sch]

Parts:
C35, C36, C37, C38, C39, C40, C41, C42, C43, C44, C45, C46: 100nF; C_0805_2012Metric
J11, J12, J13, J14, J15, J16, J17, J18, J19, J20, J21, J22: Conn_01x03_Pin; PinHeader_1x03_P2.54mm_Vertical
R14, R15, R16, R17, R18, R19, R20, R21, R22, R23, R24, R25: 100R; R_0805_2012Metric
R26, R27, R28, R29, R30, R31, R32, R33, R34, R35, R36, R37: 10k; R_0805_2012Metric

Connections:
/chip/LA_1: R14.2; also elsewhere on the board
/chip/LA_2: R15.2; also elsewhere on the board
/chip/LA_3: R16.2; also elsewhere on the board
/chip/LB_1: R22.2; also elsewhere on the board
/chip/LB_2: R23.2; also elsewhere on the board
/chip/LB_3: R24.2; also elsewhere on the board
/chip/RA_1: R17.2; also elsewhere on the board
/chip/RA_2: R18.2; also elsewhere on the board
/chip/RA_3: R19.2; also elsewhere on the board
/chip/RB_1: R20.2; also elsewhere on the board
/chip/RB_2: R21.2; also elsewhere on the board
/chip/RB_3: R25.2; also elsewhere on the board
GND: C35.1, C36.1, C37.1, C38.1, C39.1, C40.1, C41.1, C42.1, C43.1, C44.1, C45.1, C46.1, J11.3, J12.3, J13.3, J14.3, J15.3, J16.3, J17.3, J18.3, J19.3, J20.3, J21.3, J22.3, R26.2, R27.1, R28.1, R29.2, R30.1, R31.1, R32.2, R33.1, R34.1, R35.2, R36.1, R37.1; also elsewhere on the board
unnamed: J11.1, R14.1, R26.1
unnamed: J12.1, R22.1, R29.1
unnamed: J13.1, R17.1, R32.1
unnamed: J14.1, R20.1, R35.1
unnamed: J15.1, R15.1, R27.2
unnamed: J16.1, R23.1, R30.2
unnamed: J17.1, R18.1, R33.2
unnamed: J18.1, R21.1, R36.2
unnamed: J19.1, R16.1, R28.2
unnamed: J20.1, R24.1, R31.2
unnamed: J21.1, R19.1, R34.2
unnamed: J22.1, R25.1, R37.2

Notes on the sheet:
LEFT_BACK
RIGHT_BACK
LEFT_AFTER
RIGHT_AFTER

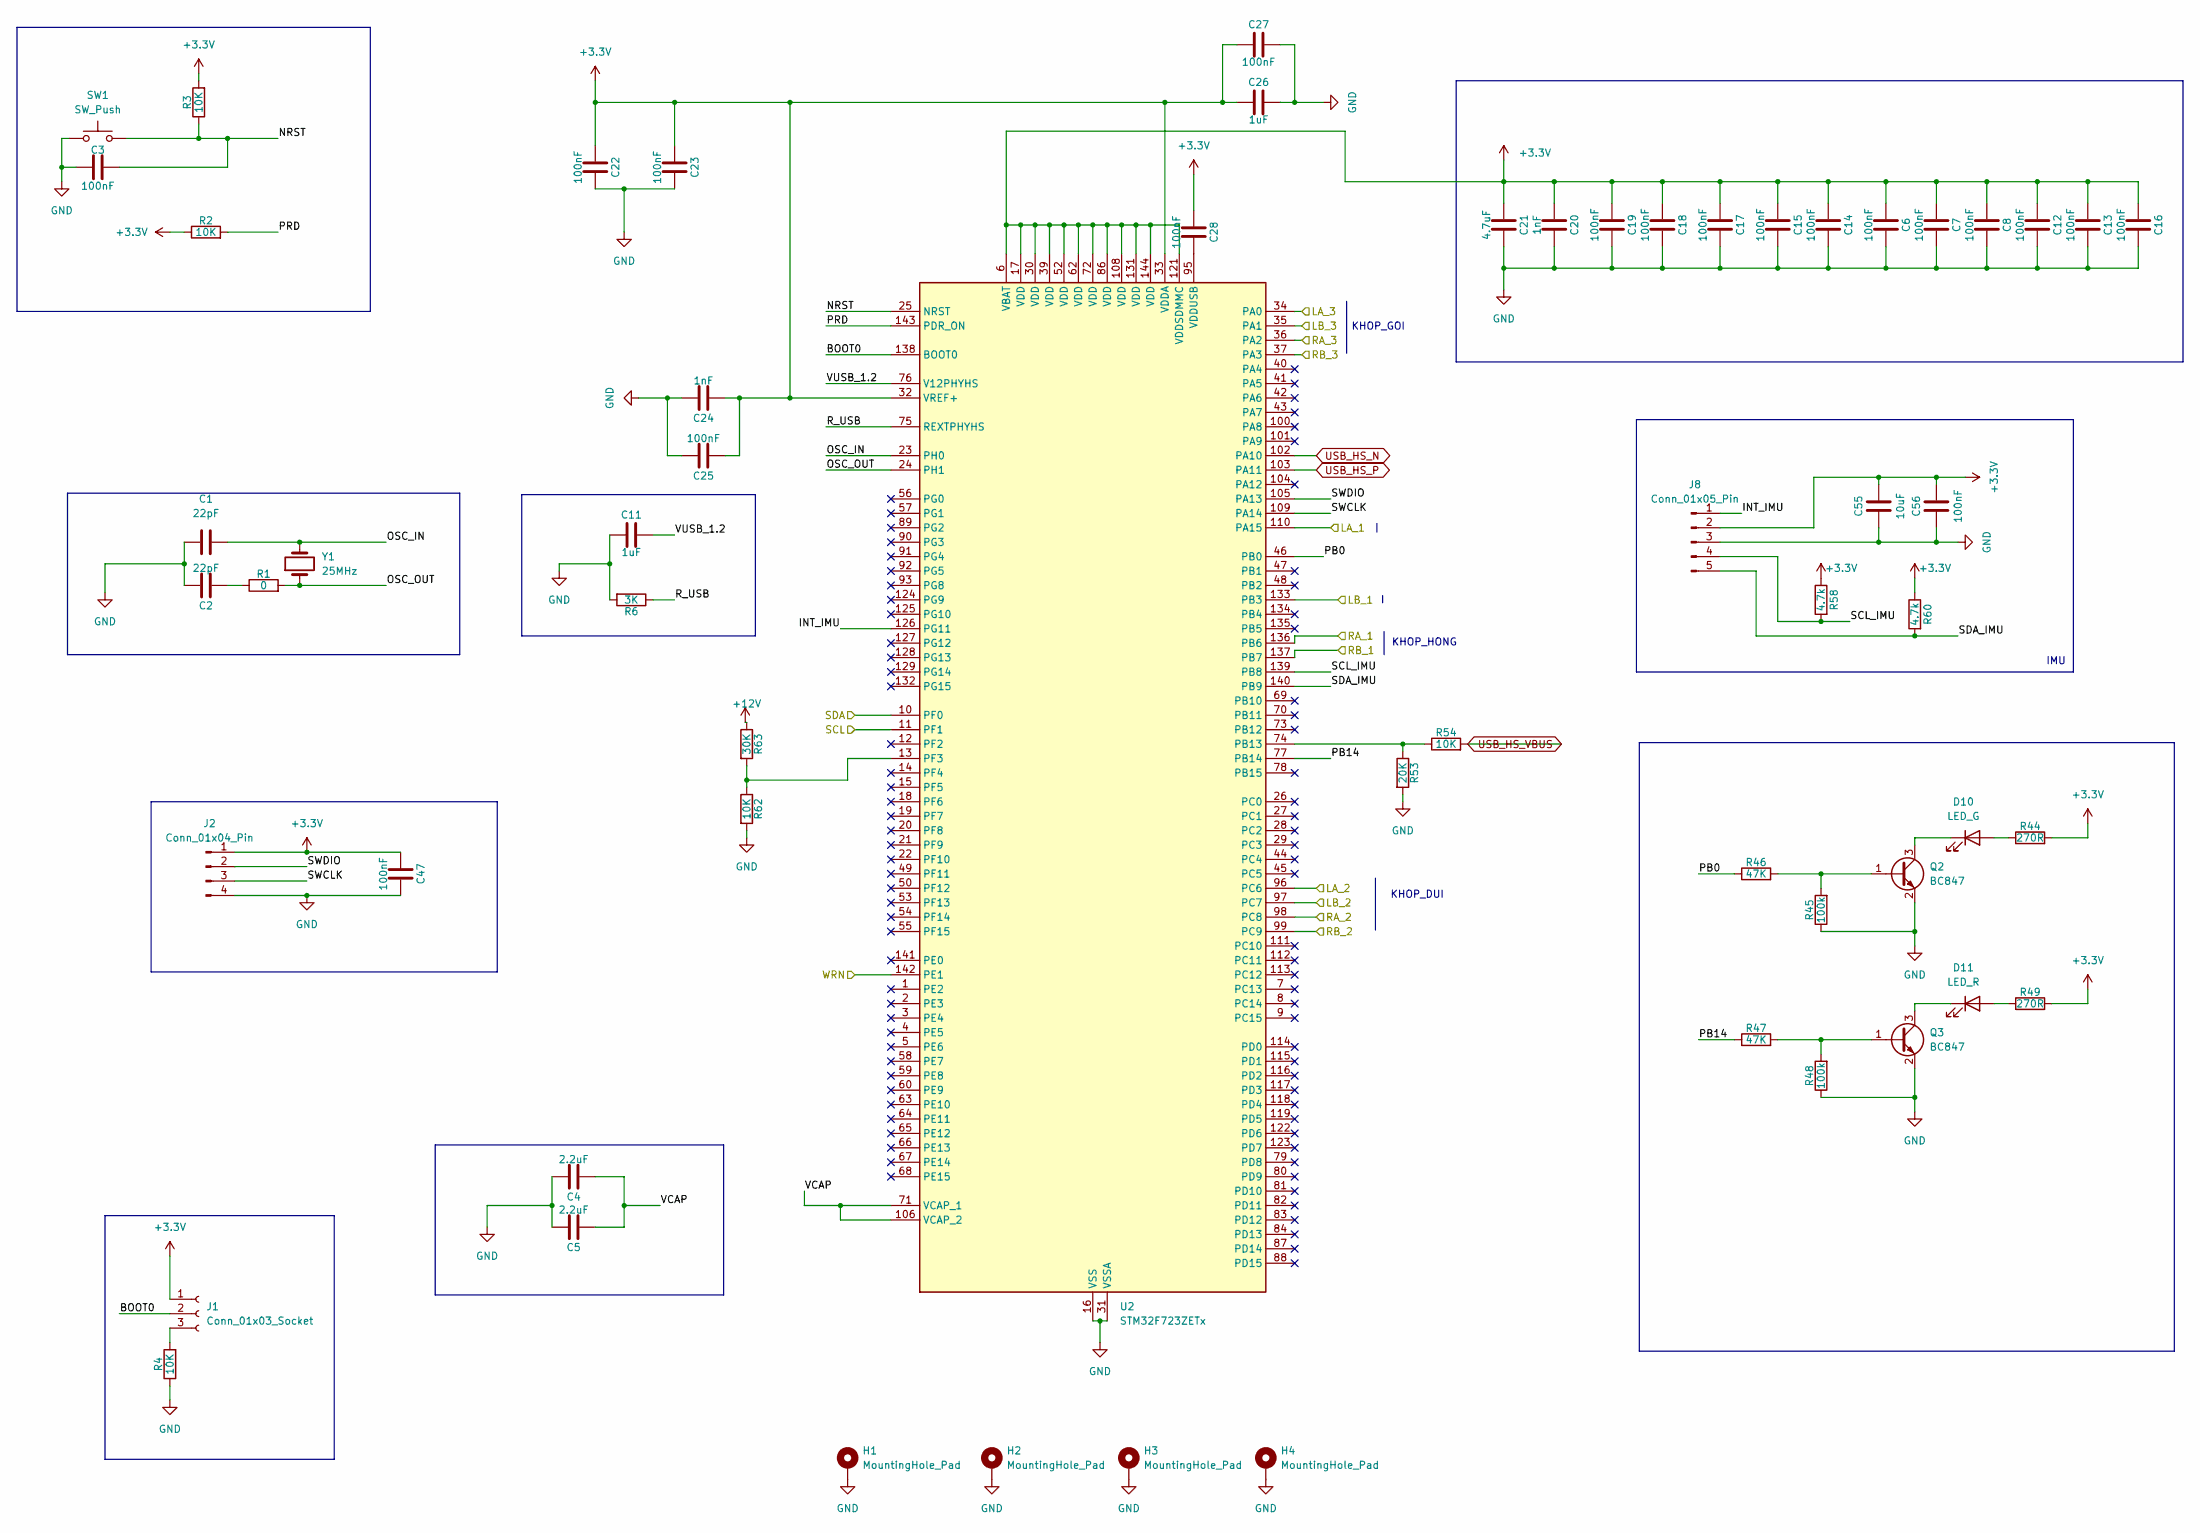
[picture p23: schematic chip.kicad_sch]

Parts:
C1, C2: 22pF; C_0805_2012Metric
C3, C6, C7, C8, C12, C13, C14, C15, C16, C17, C18, C19, C22, C23, C25, C27, C28, C47, C56: 100nF; C_0805_2012Metric
C4, C5: 2.2uF; C_0805_2012Metric
C11, C26: 1uF; C_0805_2012Metric
C20, C24: 1nF; C_0805_2012Metric
C21: 4.7uF; C_0805_2012Metric
C55: 10uF; C_0805_2012Metric
D10: LED_G; LED_0805_2012Metric
D11: LED_R; LED_0805_2012Metric
H1, H2, H3, H4: MountingHole_Pad; MountingHole_3.2mm_M3_Pad
J1: Conn_01x03_Socket; PinSocket_1x03_P2.54mm_Vertical
J2: Conn_01x04_Pin; PinSocket_1x04_P2.54mm_Vertical
J8: Conn_01x05_Pin; PinSocket_1x05_P2.54mm_Vertical
Q2, Q3: BC847; SOT-23
R1: 0; R_0805_2012Metric
R2, R3, R4, R54, R62: 10K; R_0805_2012Metric
R6: 3K; R_0805_2012Metric
R44, R49: 270R; R_0805_2012Metric
R45, R48: 100k; R_0805_2012Metric
R46, R47: 47K; R_0805_2012Metric
R53: 20K; R_0805_2012Metric
R58, R60: 4.7k; R_0805_2012Metric
R63: 30K; R_0805_2012Metric
SW1: SW_Push; SW_SMD_3x6mm
U2: STM32F723ZETx; LQFP-144_20x20mm_P0.5mm
Y1: 25MHz; Crystal_HC49-U_Vertical

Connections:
+3.3V: C6.2, C7.2, C8.2, C12.2, C13.2, C14.2, C15.2, C16.2, C17.2, C18.2, C19.2, C20.2, C21.2, C22.2, C23.2, C24.2, C25.2, C26.2, C27.2, C28.2, C47.2, C55.2, C56.2, J1.1, J2.1, J8.2, R2.1, R3.2, R44.2, R49.2, R58.1, R60.1, U2.6 (VBAT), U2.17 (VDD), U2.30 (VDD), U2.32 (VREF+), U2.33 (VDDA), U2.39 (VDD), U2.52 (VDD), U2.62 (VDD), U2.72 (VDD), U2.86 (VDD), U2.108 (VDD), U2.121 (VDDSDMMC), U2.131 (VDD), U2.144 (VDD); also elsewhere on the board
+12V: R63.1; also elsewhere on the board
/chip/BOOT0: J1.2, U2.138 (BOOT0)
/chip/INT_IMU: J8.1, U2.126 (PG11)
/chip/LA_1: U2.110 (PA15); also elsewhere on the board
/chip/LA_2: U2.96 (PC6); also elsewhere on the board
/chip/LA_3: U2.34 (PA0); also elsewhere on the board
/chip/LB_1: U2.133 (PB3); also elsewhere on the board
/chip/LB_2: U2.97 (PC7); also elsewhere on the board
/chip/LB_3: U2.35 (PA1); also elsewhere on the board
/chip/NRST: C3.2, R3.1, SW1.2, U2.25 (NRST)
/chip/OSC_IN: C1.2, U2.23 (PH0), Y1.2
/chip/OSC_OUT: R1.2, U2.24 (PH1), Y1.1
/chip/PB0: R46.1, U2.46 (PB0)
/chip/PB14: R47.1, U2.77 (PB14)
/chip/PRD: R2.2, U2.143 (PDR_ON)
/chip/RA_1: U2.136 (PB6); also elsewhere on the board
/chip/RA_2: U2.98 (PC8); also elsewhere on the board
/chip/RA_3: U2.36 (PA2); also elsewhere on the board
/chip/RB_1: U2.137 (PB7); also elsewhere on the board
/chip/RB_2: U2.99 (PC9); also elsewhere on the board
/chip/RB_3: U2.37 (PA3); also elsewhere on the board
/chip/R_USB: R6.1, U2.75 (REXTPHYHS)
/chip/SCL: U2.11 (PF1); also elsewhere on the board
/chip/SCL_IMU: J8.4, R58.2, U2.139 (PB8)
/chip/SDA: U2.10 (PF0); also elsewhere on the board
/chip/SDA_IMU: J8.5, R60.2, U2.140 (PB9)
/chip/SWCLK: J2.3, U2.109 (PA14)
/chip/SWDIO: J2.2, U2.105 (PA13)
/chip/VCAP: C4.2, C5.2, U2.71 (VCAP_1), U2.106 (VCAP_2)
/chip/VUSB_1.2: C11.1, U2.76 (V12PHYHS)
/chip/WRN: U2.142 (PE1); also elsewhere on the board
GND: C1.1, C2.1, C3.1, C4.1, C5.1, C6.1, C7.1, C8.1, C11.2, C12.1, C13.1, C14.1, C15.1, C16.1, C17.1, C18.1, C19.1, C20.1, C21.1, C22.1, C23.1, C24.1, C25.1, C26.1, C27.1, C47.1, C55.1, C56.1, H1.1 (1_1), H2.1 (1_1), H3.1 (1_1), H4.1 (1_1), J2.4, J8.3, Q2.2 (E), Q3.2 (E), R4.1, R6.2, R45.1, R48.1, R53.2, R62.2, SW1.1, U2.16 (VSS), U2.31 (VSSA), U2.38 (VSS), U2.51 (VSS), U2.61 (VSS), U2.85 (VSS), U2.94 (VSS), U2.107 (VSS), U2.120 (VSS), U2.130 (VSS); also elsewhere on the board
unnamed: C2.2, R1.1
unnamed: D10.2 (A), R44.1
unnamed: D10.1 (K), Q2.3 (C)
unnamed: D11.2 (A), R49.1
unnamed: D11.1 (K), Q3.3 (C)
unnamed: J1.3, R4.2
unnamed: Q2.1 (B), R45.2, R46.2
unnamed: Q3.1 (B), R47.2, R48.2
unnamed: R53.1, R54.1, U2.74 (PB13)
unnamed: R62.1, R63.2, U2.13 (PF3)
unnamed: C28.1, U2.95 (VDDUSB)
USB_HS_N: U2.102 (PA10); also elsewhere on the board
USB_HS_P: U2.103 (PA11); also elsewhere on the board
USB_HS_VBUS: R54.2; also elsewhere on the board

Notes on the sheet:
IMU
KHOP_HONG
KHOP_DUI
KHOP_GOI

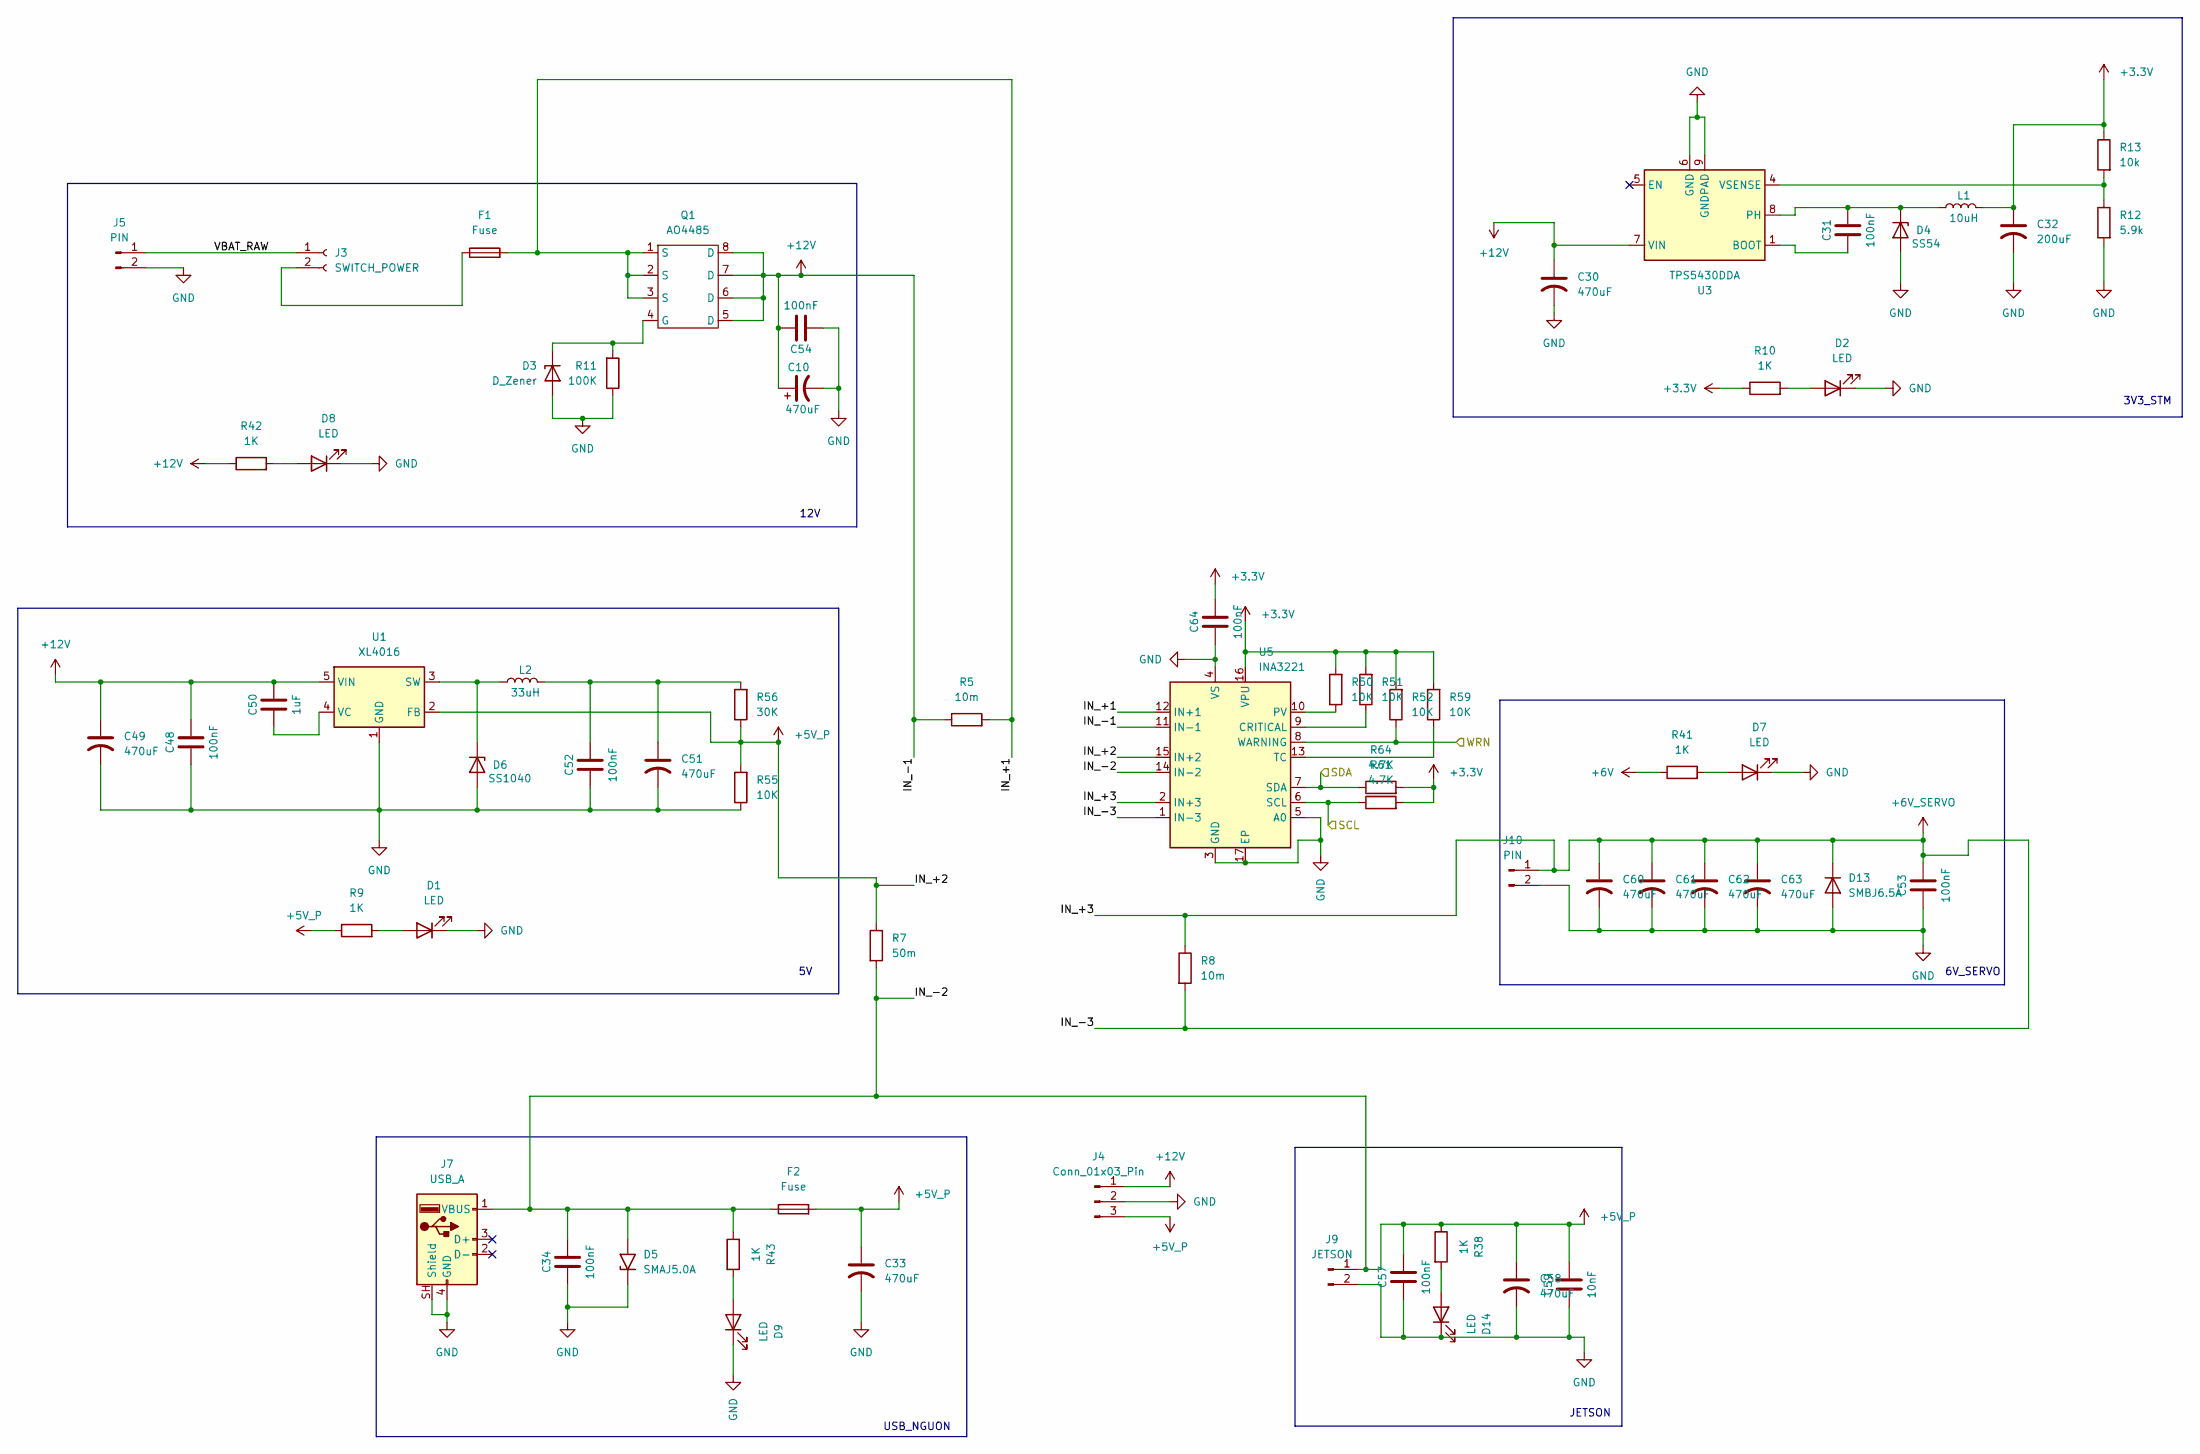
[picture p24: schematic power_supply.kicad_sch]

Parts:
C10: 470uF; CP_Radial_D10.0mm_P5.00mm
C30, C49, C51: 470uF; CP_Elec_8x10
C31, C34, C48, C52, C53, C54, C57, C64: 100nF; C_0805_2012Metric
C32: 200uF; CP_EIA-7343-31_Kemet-D_HandSolder
C33, C58, C60, C61, C62, C63: 470uF; CP_EIA-7343-31_Kemet-D_HandSolder
C50: 1uF; C_0805_2012Metric
C59: 10nF; C_0805_2012Metric
D1, D2, D7, D8, D9, D14: LED; LED_0805_2012Metric
D3: D_Zener; D_0805_2012Metric
D4: SS54; D_SMC
D5: SMAJ5.0A; D_SMA
D6: SS1040; D_SMC
D13: SMBJ6.5A; D_SMB
F1, F2: Fuse; Fuseholder_Littelfuse_100_series_5x20mm
J3: SWITCH_POWER; PinHeader_1x02_P2.54mm_Vertical
J4: Conn_01x03_Pin; PinHeader_1x03_P2.54mm_Vertical
J5, J10: PIN; TerminalBlock_Phoenix_MKDS-1,5-2-5.08_1x02_P5.08mm_Horizont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
J7: USB_A; USB_A_Molex_67643_Horizontal
J9: JETSON; TerminalBlock_Phoenix_MKDS-1,5-2-5.08_1x02_P5.08mm_Horizont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
L1: 10uH; L_12x12mm_H6mm
L2: 33uH; L_12x12mm_H6mm
Q1: AO4485; SOIC-8_3.9x4.9mm_P1.27mm
R5, R8: 10m; R_2512_6332Metric
R7: 50m; R_2512_6332Metric
R9, R10, R38, R41, R42, R43: 1K; R_0805_2012Metric
R11: 100K; R_0805_2012Metric
R12: 5.9k; R_0805_2012Metric
R13: 10k; R_0805_2012Metric
R50, R51, R52, R55, R59: 10K; R_0805_2012Metric
R56: 30K; R_0805_2012Metric
R61, R64: 4.7K; R_0805_2012Metric
U1: XL4016; TO-263-5_TabPin3
U3: TPS5430DDA; TI_SO-PowerPAD-8_ThermalVias
U5: INA3221; Texas_RGV0016A_VQFN-16-1EP_4x4mm_P0.65mm_EP2.1x2.1mm

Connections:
+3.3V: C32.1, C64.2, L1.1, R10.1, R13.1, R50.2, R51.2, R52.2, R59.2, R61.2, R64.2, U5.16 (VPU); also elsewhere on the board
+5V_P: C33.1, C34.2, C57.2, C58.1, C59.2, D5.2 (A2), F2.1, F2.2, J4.3, J7.1 (VBUS), J9.1, R7.1, R7.2, R9.1, R38.1, R43.1, R55.2, R56.1, U1.2 (FB), U5.14 (IN-2), U5.15 (IN+2)
+12V: C10.1, C30.1, C48.2, C49.1, C50.2, C54.2, J4.1, Q1.5 (D), Q1.6 (D), Q1.7 (D), Q1.8 (D), R5.1, R42.1, U1.5 (VIN), U3.7 (VIN), U5.11 (IN-1); also elsewhere on the board
/chip/SCL: R61.1, U5.6 (SCL); also elsewhere on the board
/chip/SDA: R64.1, U5.7 (SDA); also elsewhere on the board
/chip/WRN: R52.1, U5.8 (WARNING); also elsewhere on the board
/power supply/IN_+1: F1.2, Q1.1 (S), Q1.2 (S), Q1.3 (S), R5.2, U5.12 (IN+1)
/power supply/VBAT_RAW: J3.1, J5.1
GND: C10.2, C30.2, C32.2, C33.2, C34.1, C48.1, C49.2, C51.2, C52.1, C53.1, C54.1, C57.1, C58.2, C59.1, C60.2, C61.2, C62.2, C63.2, C64.1, D1.1 (K), D2.1 (K), D3.2 (A), D4.2 (A), D5.1 (A1), D6.2 (A), D7.1 (K), D8.1 (K), D9.1 (K), D13.2 (A), D14.1 (K), J4.2, J5.2, J7.4 (GND), J7.SH (Shield), J9.2, J10.2, R11.1, R12.2, R55.1, U1.1 (GND), U3.6 (GND), U3.9 (GNDPAD), U5.3 (GND), U5.4 (VS), U5.5 (A0), U5.17 (EP); also elsewhere on the board
unnamed: C51.1, C52.2, L2.1, R56.2
unnamed: D1.2 (A), R9.2
unnamed: D2.2 (A), R10.2
unnamed: D3.1 (K), Q1.4 (G), R11.2
unnamed: C31.2, D4.1 (K), L1.2, U3.8 (PH)
unnamed: D6.1 (K), L2.2, U1.3 (SW)
unnamed: D7.2 (A), R41.2
unnamed: D8.2 (A), R42.2
unnamed: D9.2 (A), R43.2
unnamed: D14.2 (A), R38.2
unnamed: F1.1, J3.2
unnamed: C50.1, U1.4 (VC)
unnamed: C31.1, U3.1 (BOOT)
unnamed: R12.1, R13.2, U3.4 (VSENSE)
unnamed: R51.1, U5.9 (CRITICAL)
unnamed: R50.1, U5.10 (PV)
unnamed: R59.1, U5.13 (TC)

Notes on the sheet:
12V
3V3_STM
6V_SERVO
JETSON
USB_NGUON

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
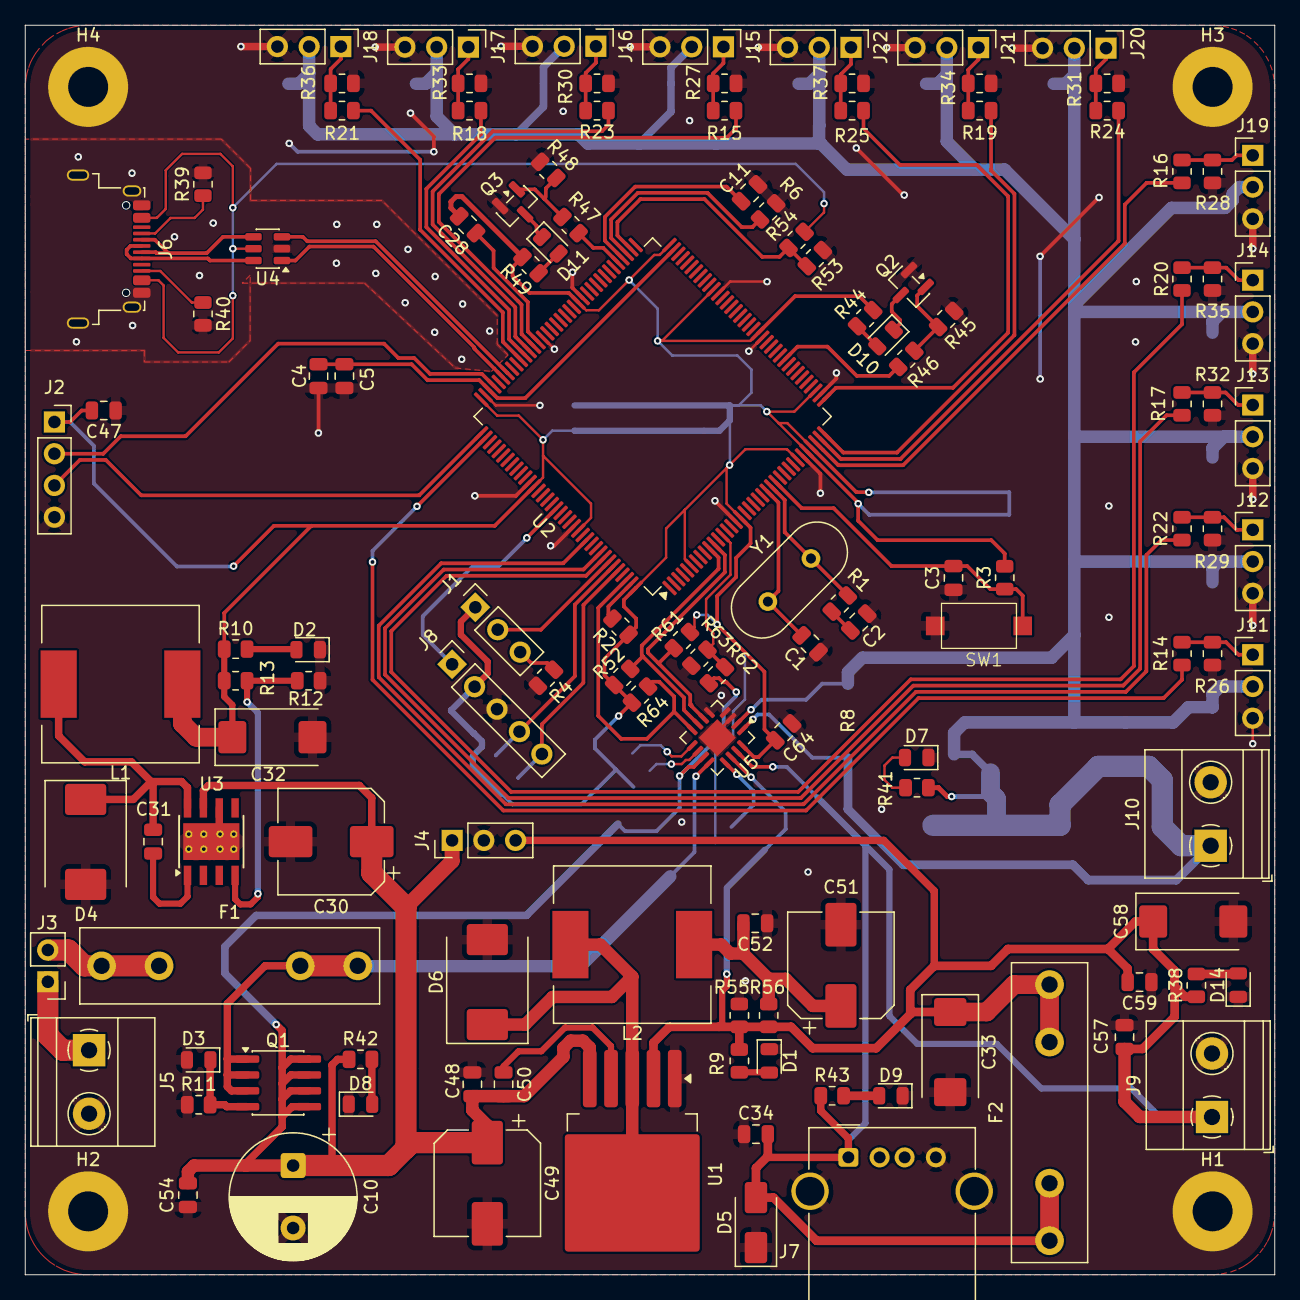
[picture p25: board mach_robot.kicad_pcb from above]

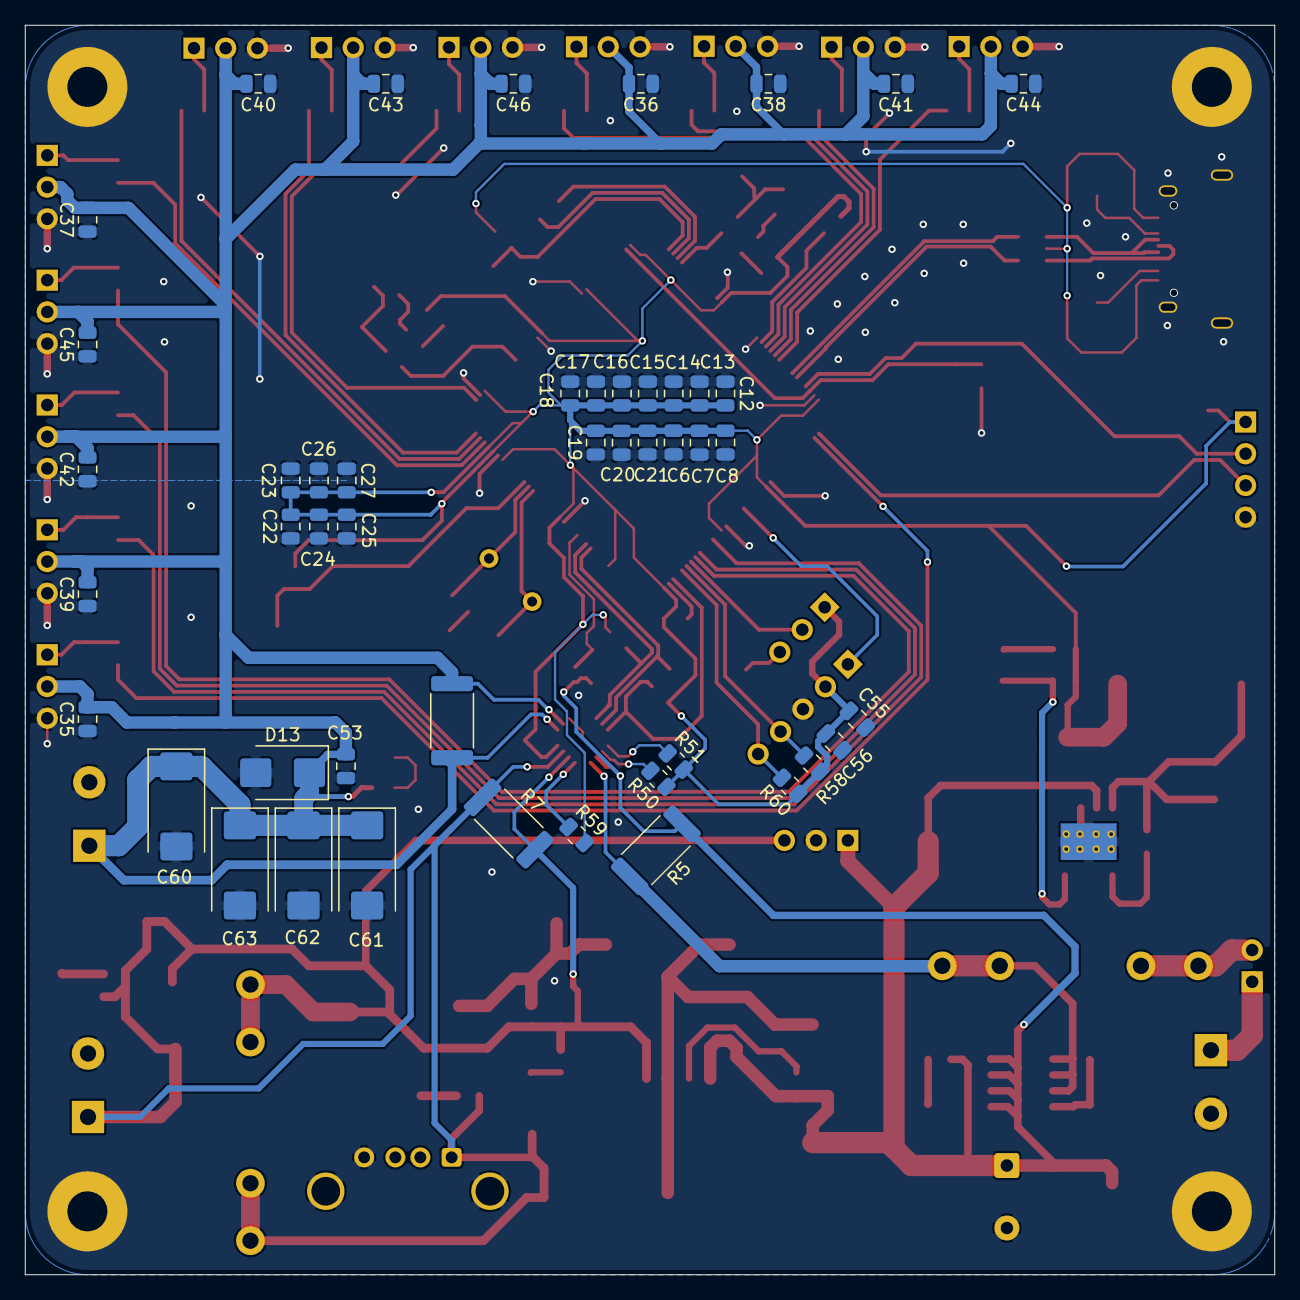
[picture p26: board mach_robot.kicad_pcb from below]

Board: 2 copper layers, 100.0 x 100.0 mm, 178 parts (47 on the bottom side), 82 nets.

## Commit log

2026-09-02 hardware: add KiCad board files
    [.kicad_sch, chip.kicad_sch, imu.kicad_sch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]
2026-09-02 hardware: add mechanical CAD files
    [3_6_2.5.SLDPRT, M2 CAP HEAD SOCKET SCREW.SLDPRT, M2 x 8 CAP HEAD SOCKET SCREW.IGS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]
2026-09-03 hardware: update CAD models
    [MirrorPart78.SLDPRT, Mirrorarm_mod_L_2.SLDPRT, Part40.SLDPRT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]
2026-09-04 pcb update
    [chip.kicad_sch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]
2026-09-05 Update PCB via size to 0.3mm and generate Gerber files
    [mach_robot-B_Cu.gbl, mach_robot-B_Mask.gbs, mach_robot-B_Paste.gbp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]
2026-09-05 Add kinematics and inverse_kinematics module
2026-09-05 Added kinematics.drawio
2026-09-07 Update CAD models, assemblies, and 3D print STL files
    [MirrorPart40.SLDPRT, Part116.SLDPRT, Part116_1.SLDPRT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]
2026-09-10 Cập nhật Untitled Diagram.drawio
2026-09-13 update urdf and kinematic
    [Calf_LB.STL, Calf_LF.STL, Calf_RB.STL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]
2026-09-14 update URDF and cad
    [Calf_LB.STL, Calf_LF.STL, Calf_RB.STL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]
2026-09-15 URDF fix
    [Calf_LB.STL, Calf_LF.STL, Calf_RB.STL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]
2026-09-15 : URDF_1 recheck
    [Calf_LB.STL, Calf_LF.STL, Calf_RB.STL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]
